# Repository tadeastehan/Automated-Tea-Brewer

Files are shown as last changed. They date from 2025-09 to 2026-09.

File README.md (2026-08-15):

<div align="center">

# Automated Tea Brewer

### Design and Implementation of a Fully Automated ESP32-Based Tea Brewer





`ESP32` · `Embedded Systems` · `C` · `FreeRTOS` · `LVGL` · `TMC2130` · `Stepper Motor` · `IoT`

[Repository](https://github.com/tadeastehan/Automated-Tea-Brewer) · [Documentation](#documentation) · [Getting Started](#project-structure)

</div>

---

<p align="center">
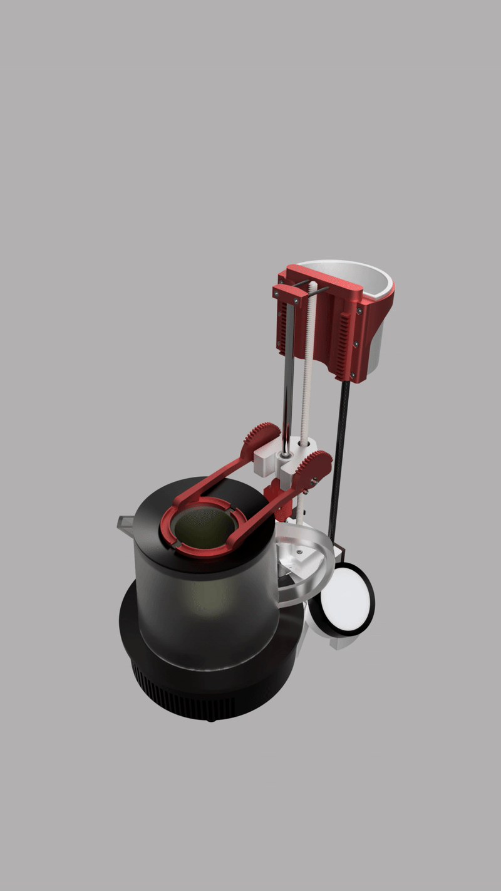
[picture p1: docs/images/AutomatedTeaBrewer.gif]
Automated Tea Brewer Animation
  
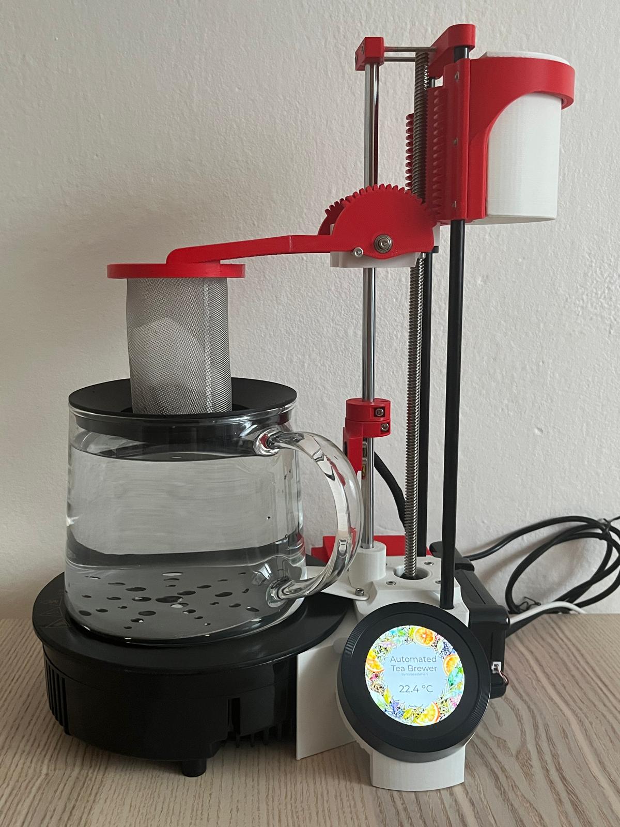
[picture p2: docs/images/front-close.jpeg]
Automated Tea Brewer Front View
  
</p>

## Project Annotation

This project presents the design and implementation of a **fully automated tea brewing system** based on ESP32 microcontrollers. The system consists of two ESP32 modules working in tandem:

| Module | Microcontroller | Function |
| --- | --- | --- |
| **Display Controller** | ESP32-S3 | Touchscreen UI using LVGL graphics library |
| **Motor Controller** | ESP32-C6 | Stepper motor control via TMC2130 driver |

### Key Features

- **IR Thermometer** - Precise water temperature monitoring
- **Laser Distance Sensor** - Teapot presence detection (VL53L0X)
- **Induction Cooker Interface** - Automated heating control via optocoupler
- **Stepper Motor Control** - Precise tea bag immersion with TMC2130
- **Touchscreen Interface** - Intuitive LVGL-based user interface
- **Web Dashboard** - Remote control via WiFi with mDNS support (teabrewer.local)
- **Programmable Brewing** - Configurable temperature, steeping time, and movement

> The goal was to create a fully autonomous tea brewing appliance that can prepare tea with consistent quality by precisely controlling brewing temperature, steeping time, and tea bag movement.

---

## Documents

| Document | Path |
| --- | --- |
| Paper | [View Paper](docs/paper/Design_and_Implementation_of_a_Fully_Automated_ESP32_Based_Tea_Brewer___Tadeáš_Těhan%20(3).pdf) |
| Images & Screenshots | [View Images](docs/images/) |

---

## Project Structure

```
Automated-Tea-Brewer/
├── src/                          # Source code
│   ├── tea-brewer/               # ESP32-S3 Display Controller
│   │   ├── main/
│   │   │   ├── app_main.c           # Application entry point
│   │   │   ├── uart_comm.c/h        # UART communication
│   │   │   ├── settings.c/h         # User settings management
│   │   │   ├── webserver.c/h        # Web dashboard server
│   │   │   └── ui/                  # LVGL user interface
│   │   ├── components/
│   │   │   ├── bsp/                 # Board Support Package
│   │   │   └── esp_lcd_touch_cst816s/
│   │   └── managed_components/      # ESP-IDF dependencies
│   │
│   └── tea-brewer-controller/    # ESP32-C6 Motor Controller
│       ├── main/
│       │   ├── main.c               # Application entry point
│       │   ├── motor/               # TMC2130 stepper control
│       │   ├── temperature_sensor/  # IR thermometer interface
│       │   ├── distance_sensor/     # VL53L0X laser sensor
│       │   ├── pot_sensor/          # Teapot detection
│       │   ├── protocol/            # ESP-to-ESP communication
│       │   ├── console/             # USB Serial debug interface
│       │   ├── scheduler.c/h        # Task scheduling
│       │   └── rtc/                 # Real-time clock
│       └── components/
│           └── vl53l0x/             # Distance sensor driver
│
├── docs/                         # Documentation
│   ├── electronics/                 # Electronics documentation
│   ├── images/                      # Project images & photos
│   ├── induction-cooker/            # Induction cooker mod guide
│   ├── stepper-motor-driver/        # TMC2130 wiring diagrams
│   └── web-dashboard/               # Web dashboard documentation
│
├── models/                       # 3D Models
│
└── reports/                      # Data & Analysis
    ├── brew-time/                   # Brew time analysis
    │   ├── graph_maker.py
    │   ├── data/
    │   └── graphs/
    ├── heat-dissipation/            # Heat dissipation analysis
    │   ├── graph_maker.py
    │   ├── data/
    │   └── graphs/
    └── ir-thermometer/              # IR thermometer calibration
        ├── graph_maker.py
        ├── data/
        └── graphs/
```

---

## Documentation

Hardware setup guides are available in the `docs/` folder:

- **[Induction Cooker Modification](docs/induction-cooker/induction_cooker.md)** - Optocoupler wiring and connector setup
- **[TMC2130 Stepper Driver](docs/stepper-motor-driver/TMC2130.md)** - SPI configuration and wiring diagrams
- **[Web Dashboard](docs/web-dashboard/web_dashboard.md)** - Remote control interface and API reference
- **[UI Documentation](src/ui/UI.md)** - LVGL UI structure and customization

---

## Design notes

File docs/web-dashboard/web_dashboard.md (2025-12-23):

# Tea Brewer Web Dashboard

The Tea Brewer includes a web-based dashboard that provides remote control and monitoring capabilities over WiFi. The dashboard mirrors the functionality of the physical LVGL display, allowing you to brew tea from any device on your network.

## Accessing the Dashboard

### Initial Setup (Captive Portal)

On first boot or after a WiFi reset, the Tea Brewer creates an Access Point (AP) for configuration:

1. **Connect to the AP** - Look for a WiFi network named `TeaBrewer` (or similar)
2. **Captive Portal** - A configuration page will automatically open
3. **Enter WiFi Credentials** - Provide your home WiFi network name and password
4. **Save & Connect** - The device will restart and connect to your network

### Accessing the Dashboard

Once connected to your WiFi network, access the dashboard via:

- **mDNS**: `http://teabrewer.local` (recommended)
- **IP Address**: Check your router or serial monitor for the assigned IP

## Dashboard Screenshot

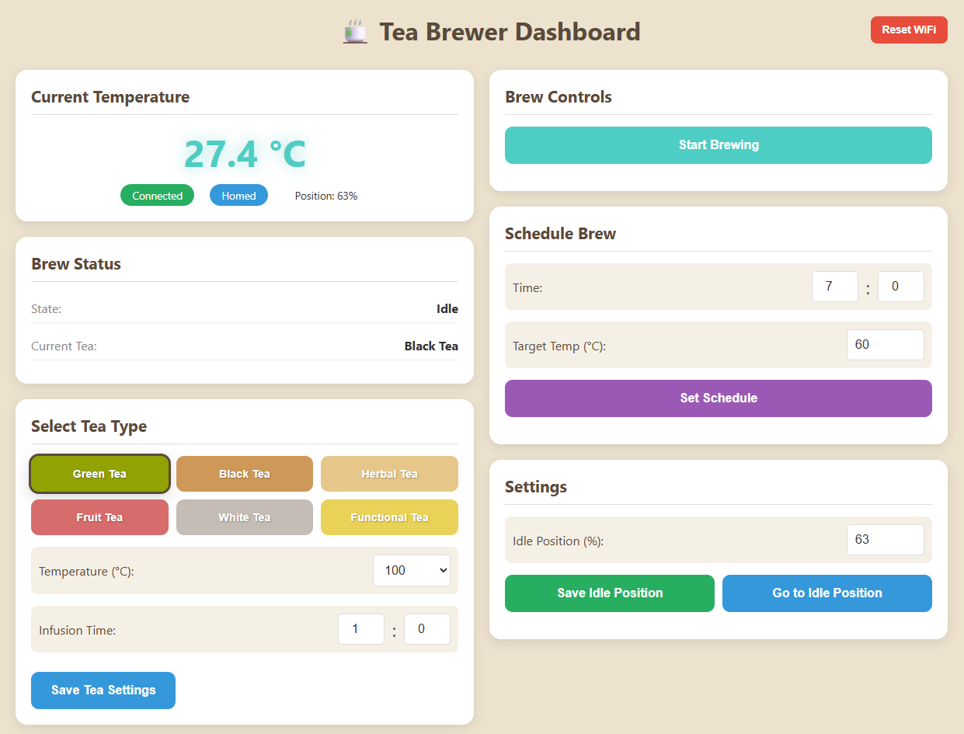
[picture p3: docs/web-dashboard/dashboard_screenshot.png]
Tea Brewer Dashboard


## Features

### Current Temperature
- **Real-time temperature display** with glowing effect
- **Motor status indicators**:
  - Connection status (Connected/Disconnected)
  - Homing status (Homed/Not Homed)
  - Current position percentage

### Brew Status
- **Current state**: Idle, Brewing, Infusing, Teabag Dropoff, or Scheduled
- **Current tea type** being brewed
- **Progress bar** during active brewing (shows percentage complete)

### Select Tea Type
- **6 tea types** with color-coded buttons:
  - Green Tea
  - Black Tea
  - Herbal Tea
  - Fruit Tea
  - White Tea
  - Functional Tea
- **Temperature setting** (75°C - 100°C in 5° increments)
- **Infusion time** configuration (minutes and seconds)
- **Save Tea Settings** button to persist changes

### Brew Controls
- **Start Brewing** - Begin brewing with the selected tea type
- **Stop** - Emergency stop during brewing

### Schedule Brew
- **Set time** (hour and minute) for scheduled brewing
- **Target temperature** for pre-heating
- **Set Schedule** / **Cancel Schedule** buttons
- Visual indicator showing scheduled time

### Settings
- **Idle Position** - Set and save the motor's idle/rest position
- **Go to Idle Position** - Move motor to the saved idle position

### Reset WiFi
- **Reset WiFi button** (top-right corner)
- Clears saved WiFi credentials
- Restarts device in AP mode for reconfiguration
- Confirmation dialog to prevent accidental resets

## Technical Details

### API Endpoints

| Endpoint | Method | Description |
|---|---|---|
| `/` | GET | Dashboard HTML page |
| `/api/status` | GET | Current system status (JSON) |
| `/api/tea/:index` | GET | Get tea settings for index 0-5 |
| `/api/tea/:index` | POST | Save tea settings |
| `/api/brew` | POST | Start brewing |
| `/api/brew/stop` | POST | Stop brewing |
| `/api/schedule` | POST | Set scheduled brew |
| `/api/schedule/cancel` | POST | Cancel scheduled brew |
| `/api/settings/idle_position` | POST | Save idle position |
| `/api/motor/go_idle` | POST | Move to idle position |
| `/api/wifi/reset` | POST | Reset WiFi and restart |

### Network Features

- **mDNS (Bonjour)** - Access via `teabrewer.local`
- **HTTP Server** - Port 80
- **Auto-refresh** - Status updates every 1 second
- **Toast Notifications** - Visual feedback for all actions

### Browser Compatibility

The dashboard works on all modern browsers:
- Chrome / Edge
- Firefox
- Safari (macOS / iOS)
- Android browsers

## Toast Notifications

The dashboard provides visual feedback through toast notifications:

| Action | Message | Type |
|---|---|---|
| Save tea settings | "Tea settings saved!" | Success |
| Start brew | "Brewing started!" | Success |
| Stop brew | "Brewing stopped" | Warning |
| Set schedule | "Schedule set for HH:MM" | Success |
| Cancel schedule | "Schedule cancelled" | Warning |
| Save idle position | "Idle position saved!" | Success |
| Go to idle | "Moving to idle position..." | Info |
| Reset WiFi | "Resetting WiFi..." | Warning |
| Any failure | "Failed to..." | Error |

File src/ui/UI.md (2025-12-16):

# Tea Brewer UI Documentation

## Overview

The Automated Tea Brewer uses **LVGL (Light and Versatile Graphics Library) v9.2.2** for its graphical user interface, designed using **SquareLine Studio 1.5.4**. The UI runs on an ESP32-S3 microcontroller with a round 480x480 display, providing an intuitive touch-based experience for brewing tea.

## Design Features

### Theme System

- **Dynamic Tea Colors**: The UI theme adapts based on the selected tea type, with each tea having its unique color scheme
- **Consistent Styling**: All screens share a common background and typography style using the Montserrat font family
- **Touch Optimized**: Large buttons (100x100 px) ensure easy interaction on the touchscreen

### Tea Types and Colors

The system supports 6 tea types, each with a distinct color:

| Tea Type | Color Code | Description |
| --- | --- | --- |
| Green Tea | `#92A202`  | <code style="color: #92A202">Vibrant green</code> |
| Black Tea | `#CE9958`  | <code style="color: #CE9958">Warm brown</code> |
| Herbal Tea | `#E7C789`  | <code style="color: #E7C789">Soft golden</code> |
| Fruit Tea | `#D76C6C`  | <code style="color: #D76C6C">Coral red</code> |
| White Tea | `#C4BCB5`  | <code style="color: #C4BCB5">Subtle gray</code> |
| Functional Tea | `#E9D257`  | <code style="color: #E9D257">Bright yellow</code> |

## Screen Descriptions

### 1. Main Screen

The welcome screen displaying the "Automated Tea Brewer" title with the current temperature.

- **Tap Left Side**: Navigate to Settings Screen
- **Tap Right Side**: Navigate to Tea Screen (starts with Green Tea)

### 2. Tea Screen

Displays the currently selected tea type with a themed background image.

- **Begin Button** (Play icon): Navigate to Brew Now or Scheduler Screen
- **Edit Button** (Cookie icon): Navigate to Tea Properties Screen
- **Tap Right Side**: Navigate to next tea (on last tea → Settings Screen)
- **Tap Left Side**: Navigate to previous tea (on first tea → Main Screen)

> **Navigation Loop**: Main Screen → Green Tea → Black Tea → Herbal Tea → Fruit Tea → White Tea → Functional Tea → Settings Screen → Main Screen (circular)

### 3. Tea Properties Screen

Configure brewing parameters for the selected tea:

- **Temperature Roller**: Set brewing temperature (75°C - 100°C in 5°C increments)
- **Infusion Time Rollers**: Set minutes (0-14) and seconds (0-59)
- **Return Button** (Check icon): Save and return to Tea Screen

### 4. Brew Now or Scheduler Screen

Choose between immediate brewing or scheduled brewing:

- **Brew Now Button** (Coffee cup icon): Start brewing immediately
- **Schedule Button** (Clock icon): Navigate to Scheduler Screen
- **Cancel Button** (X icon): Return to Tea Screen

### 5. Teapot Screen

Instructions to place the teapot with water on the designated area.

- Displays a teapot image with placement instructions
- Automatically proceeds when pot is detected

### 6. Brew/Infuse Screen

Active brewing progress display:

- **Progress Arc**: Visual indicator of brewing progress
- **Temperature Display**: Current and target temperature
- **Stop Button** (Stop icon): Cancel brewing and return to Tea Screen

### 7. Scheduler Screen

Configure scheduled brewing:

- **Temperature Roller**: Set target temperature (75°C - 100°C)
- **Time Rollers**: Set hour (0-23) and minute (0-59) for scheduled start
- **Confirm Button** (Check icon): Start scheduled brewing → Navigate to Scheduled Screen
- **Cancel Button** (X icon): Return to Tea Screen

### 8. Scheduled Screen

Displays scheduled brewing information:

- Shows target temperature and scheduled time
- **Cancel Button** (Stop icon): Cancel scheduled brewing and return to Tea Screen

### 9. Settings Screen

Configure system settings:

- **Idle Position Controls**: Adjust the teabag holder idle position (+/- buttons)
- **Tap Left Side**: Navigate to last tea (Functional Tea)
- **Tap Right Side**: Navigate to Main Screen

### 10. Error Screen

Displays error information when issues occur:

- **Error Text Area**: Shows detailed error message
- **Acknowledge Button** (Check icon): Return to Tea Screen

---

## Tea Brewer UI Navigation Map

```mermaid
flowchart TD
    subgraph Main["Main Screen"]
        MS[Automated Tea Brewer<br/>Shows current temperature]
    end

    subgraph TeaSelection["Tea Selection"]
        TS[Tea Screen<br/>Shows tea type & background]
    end

    subgraph TeaConfig["Tea Configuration"]
        TPS[Tea Properties Screen<br/>Temperature & Infusion Time]
    end

    subgraph BrewChoice["Brew Options"]
        BNOS[Brew Now or Scheduler Screen<br/>Choose brew timing]
    end

    subgraph Brewing["Active Brewing"]
        POT[Teapot Screen<br/>Place teapot instruction]
        BIS[Brew/Infuse Screen<br/>Progress & Controls]
    end

    subgraph Scheduling["Scheduling"]
        SCH[Scheduler Screen<br/>Set time & temperature]
        SCHD[Scheduled Screen<br/>Shows scheduled info]
    end

    subgraph Settings["Settings"]
        SET[Settings Screen<br/>Idle position controls]
    end

    subgraph Errors["Error Handling"]
        ERR[Error Screen<br/>Error details]
    end

    %% Main Navigation
    MS -->|"Tap Right Side"| TS
    MS -->|"Tap Left Side"| SET

    %% Tea Screen Navigation
    TS -->|"Tap Right Side<br/>(next tea)"| TS
    TS -->|"Tap Left Side<br/>(previous tea)"| TS
    TS -->|"First tea<br/>Tap Left Side"| MS
    TS -->|"Last tea<br/>Tap Right Side"| SET
    TS -->|"Begin Button<br/>(Play icon)"| BNOS
    TS -->|"Edit Button<br/>(Cookie icon)"| TPS

    %% Tea Properties Navigation
    TPS -->|"Return Button<br/>(Check icon)"| TS

    %% Brew Now or Scheduler Navigation
    BNOS -->|"Cancel Button<br/>(X icon)"| TS
    BNOS -->|"Brew Now Button<br/>(Coffee cup)"| POT
    BNOS -->|"Schedule Button<br/>(Clock icon)"| SCH

    %% Teapot Screen Navigation
    POT -->|"Pot detected<br/>(automatic)"| BIS

    %% Brew/Infuse Screen Navigation
    BIS -->|"Stop Button<br/>(Stop icon)"| TS
    BIS -->|"Brewing Complete<br/>(automatic)"| TS

    %% Scheduler Screen Navigation
    SCH -->|"Cancel Button<br/>(X icon)"| TS
    SCH -->|"Confirm Button<br/>(Check icon)"| SCHD

    %% Scheduled Screen Navigation
    SCHD -->|"Cancel Button<br/>(Stop icon)"| TS
    SCHD -->|"Scheduled time reached"| POT

    %% Settings Navigation
    SET -->|"Tap Right Side"| MS
    SET -->|"Tap Left Side"| TS

    %% Error Screen Navigation
    ERR -->|"Acknowledge Button<br/>(Check icon)"| TS

    %% Error can occur from multiple screens
    BIS -.->|"Error occurs"| ERR
    POT -.->|"Error occurs"| ERR

    %% Styling
    style MS fill:#1a1a2e,stroke:#92A202,color:#fff
    style TS fill:#1a1a2e,stroke:#92A202,color:#fff
    style TPS fill:#1a1a2e,stroke:#CE9958,color:#fff
    style BNOS fill:#1a1a2e,stroke:#E7C789,color:#fff
    style POT fill:#1a1a2e,stroke:#D76C6C,color:#fff
    style BIS fill:#1a1a2e,stroke:#FF5B2B,color:#fff
    style SCH fill:#1a1a2e,stroke:#E9D257,color:#fff
    style SCHD fill:#1a1a2e,stroke:#E9D257,color:#fff
    style SET fill:#1a1a2e,stroke:#C4BCB5,color:#fff
    style ERR fill:#1a1a2e,stroke:#FF0000,color:#fff
```

---

## Screen Gallery

| Screen Name | Screenshot |
| --- | --- |
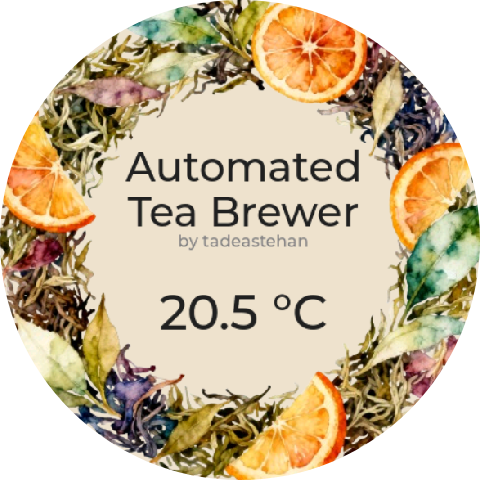
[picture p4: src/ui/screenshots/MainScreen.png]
Main Screen
| Main Screen |  |
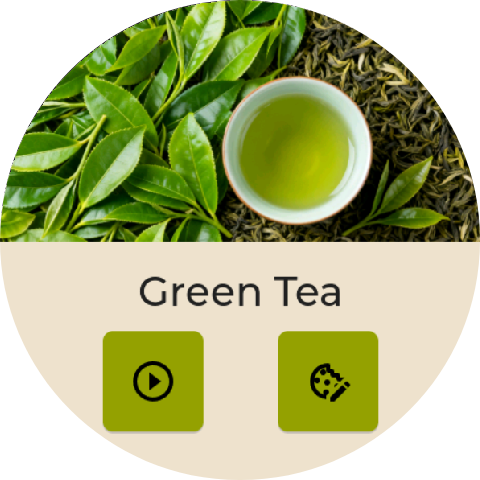
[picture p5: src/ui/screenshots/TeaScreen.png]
Tea Screen
| Tea Screen |  |
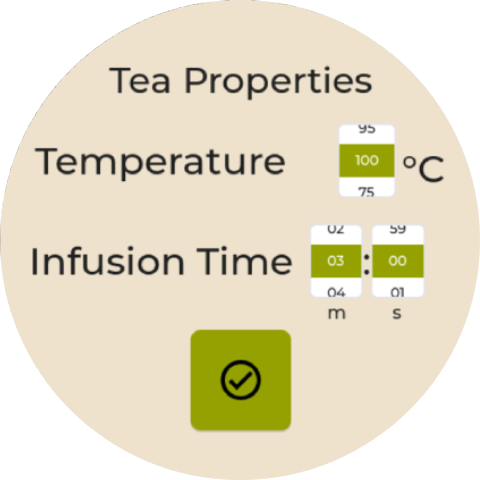
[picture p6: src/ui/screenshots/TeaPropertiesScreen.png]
Tea Properties Screen
| Tea Properties Screen |  |
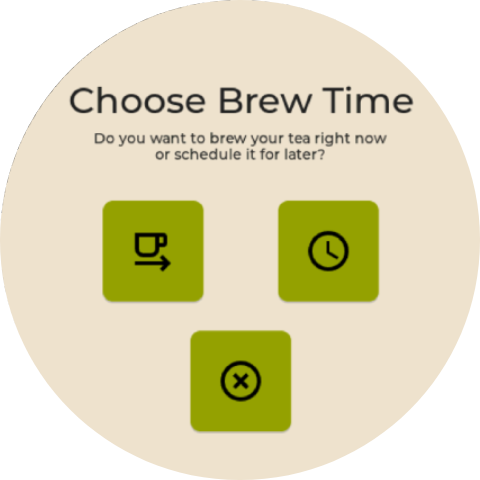
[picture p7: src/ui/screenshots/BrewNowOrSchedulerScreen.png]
Brew Now or Scheduler Screen
| Brew Now or Scheduler Screen |  |
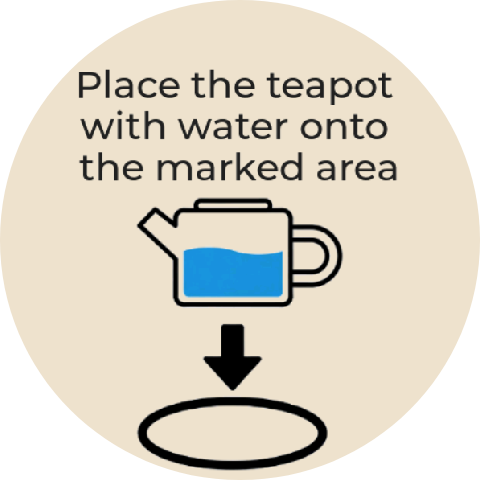
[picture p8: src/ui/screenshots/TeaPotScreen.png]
Teapot Screen
| Teapot Screen |  |
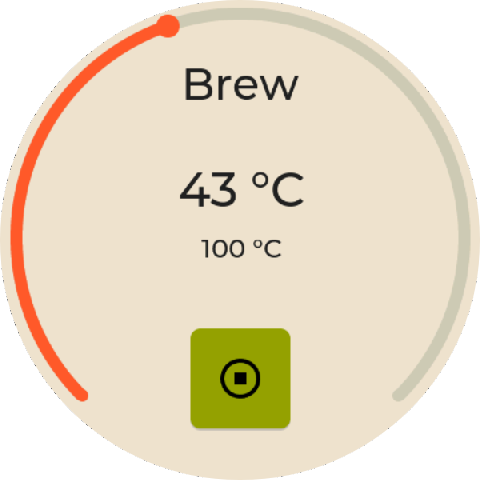
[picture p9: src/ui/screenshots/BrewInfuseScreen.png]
Brew/Infuse Screen
| Brew/Infuse Screen |  |
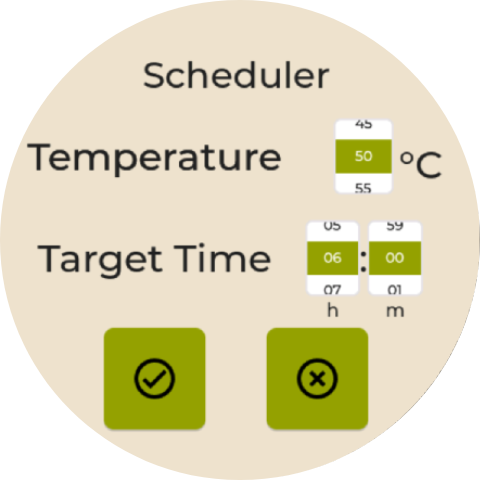
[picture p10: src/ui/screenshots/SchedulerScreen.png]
Scheduler Screen
| Scheduler Screen |  |
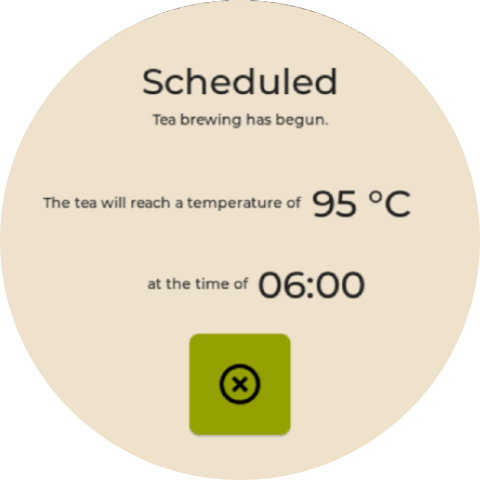
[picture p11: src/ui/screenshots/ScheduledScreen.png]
Scheduled Screen
| Scheduled Screen |  |
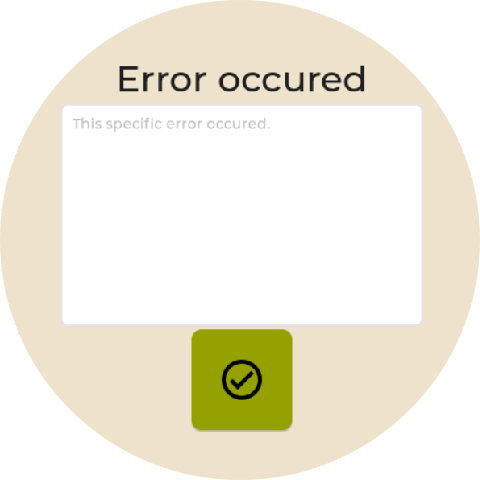
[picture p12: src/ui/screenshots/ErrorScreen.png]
Error Screen
| Error Screen |  |
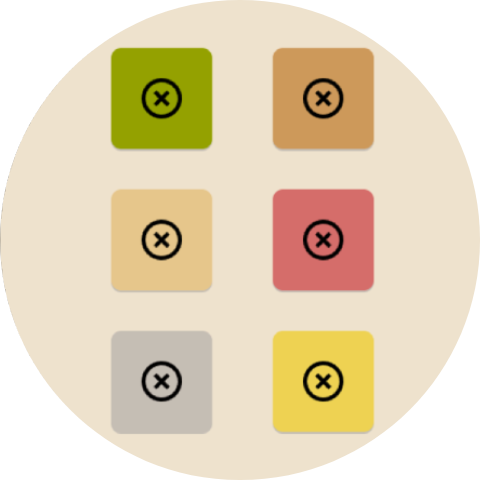
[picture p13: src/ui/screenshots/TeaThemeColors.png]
Tea Theme Colors
| Tea Theme Colors |  |

---

## Technical Details

### Screen IDs

```c
#define UI_SCREEN_MAIN              0
#define UI_SCREEN_TEA               1
#define UI_SCREEN_TEAPOT            2
#define UI_SCREEN_BREW_INFUSE       3
#define UI_SCREEN_ERROR             4
#define UI_SCREEN_TEA_PROPERTIES    5
#define UI_SCREEN_BREW_NOW_OR_SCHEDULER 6
#define UI_SCREEN_SETTINGS          7
#define UI_SCREEN_SCHEDULER         8
#define UI_SCREEN_SCHEDULED         9
```

### File Structure

```
src/tea-brewer/main/ui/
├── ui.c / ui.h              # Main UI initialization
├── ui_events.c / ui_events.h # Event handlers
├── ui_helpers.c / ui_helpers.h # Helper functions
├── ui_themes.c / ui_themes.h # Theme definitions
├── screens/                  # Individual screen files
│   ├── ui_MainScreen.c/h
│   ├── ui_TeaScreen.c/h
│   ├── ui_TeaPropertiesScreen.c/h
│   ├── ui_BrewNowOrSchedulerScreen.c/h
│   ├── ui_TeapotScreen.c/h
│   ├── ui_BrewInfuseScreen.c/h
│   ├── ui_SchedulerScreen.c/h
│   ├── ui_ScheduledScreen.c/h
│   ├── ui_SettingsScreen.c/h
│   └── ui_ErrorScreen.c/h
├── fonts/                    # Font assets
└── images/                   # Image assets
```

### SquareLine Studio Project

The UI design source files are located in:

```
src/ui/SquareLine-Project/
├── Automated-Tea-Brewer.spj  # Main project file
├── Automated-Tea-Brewer.sll  # Layout file
├── Themes.slt                # Theme definitions
└── assets/                   # Design assets
```

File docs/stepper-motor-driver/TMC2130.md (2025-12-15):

# TMC2130

The TMC2130 is a popular stepper motor driver known for its quiet operation and advanced features. It is widely used in 3D printers, CNC machines, and other applications requiring precise motor control.

## SPI Interface

> [!IMPORTANT]
> Important for proper operation: The TMC2130 V1.1 must be configured to operate in SPI mode. By default, it may be set to a different mode, so the following modifications are necessary.

The TMC2130 communicates via the SPI (Serial Peripheral Interface) protocol. This allows for high-speed data transfer and the ability to configure various parameters of the driver.
To switch the TMC2130 V1.1 into SPI mode:

- unsolder the `R5` resistor on the driver board (red rectangle in the image).
- solder `CFG4` to `GND` (purple rectangle in the image).
- solder `CFG5` to `VIO` (pink rectangle in the image).
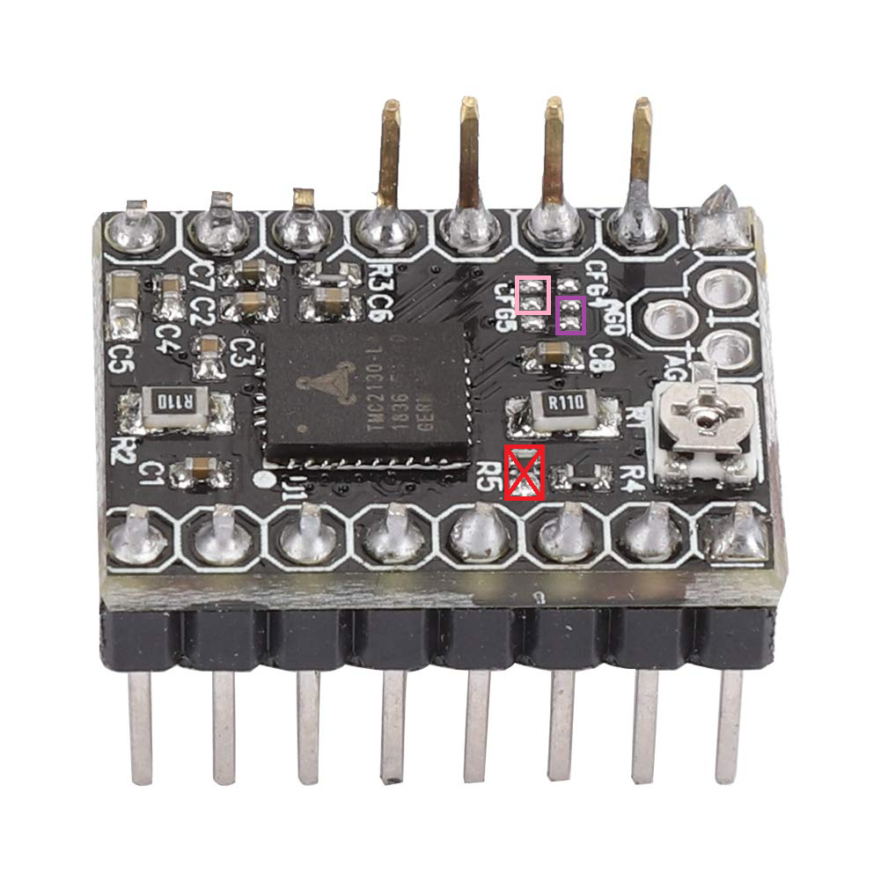
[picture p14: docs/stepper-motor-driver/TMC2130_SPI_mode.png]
TMC2130 SPI Mode
  

## Wiring
When using the TMC2130 in SPI mode, the following connections are typically made:
- **GND**: Connect to ground.
- **VIO**: Connect to 3.3V or 5V logic level (depending on your microcontroller).
- **M1A, M1B, M2A, M2B**: Connect to the stepper motor coils.
- **VM**: Connect to the motor power supply (typically 12V or 24V).
- **EN**: Connect to a digital pin on the microcontroller to enable/disable the driver.
- **SDI**: Connect to the microcontroller's MOSI pin.
- **SCK**: Connect to the microcontroller's SCK pin.
- **CS**: Connect to a digital pin on the microcontroller to select the TMC2130.
- **SDO**: Connect to the microcontroller's MISO pin.
- **STEP**: Connect to a digital pin on the microcontroller to control stepping.
- **DIR**: Connect to a digital pin on the microcontroller to control direction.
See the wiring diagram[^1] below for reference:
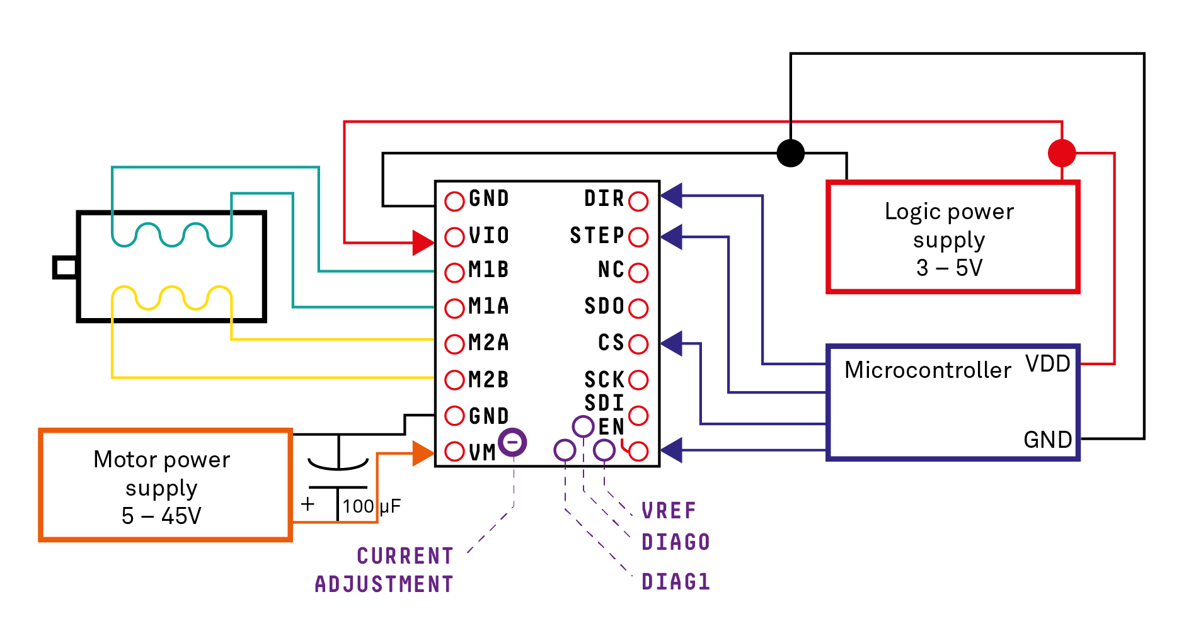
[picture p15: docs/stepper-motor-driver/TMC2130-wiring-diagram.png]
TMC2130 Wiring Diagram


[^1]: [TMC2130 Arduino Wiring](https://www.julian-h.de/sketch/tmc2130-arduino-wiring/)

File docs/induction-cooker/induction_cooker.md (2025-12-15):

# Induction Cooker

## Prerequisites

### Optocoupler

Optocoupler is required to isolate the high voltage part of the induction cooker from the low voltage ESP32 controller. We recommend using `PC817` optocoupler.
To use the induction cooker with ESP32 we need to modify the hardware slightly. So we open the induction cooker and controller board and connect `PC817` optocoupler pins `emitter` to the one leg of a button and `collector` to the other leg of the button. Then between the `anode` and connector pins of the optocoupler we connect a `150 Ω` resistor in series (I = 20mA at 3.3V).
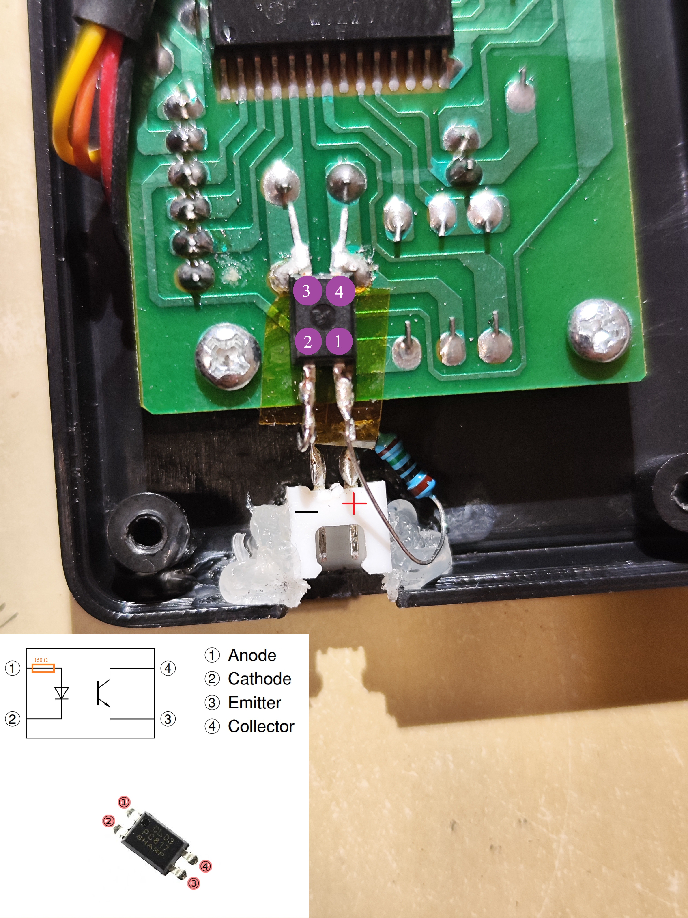
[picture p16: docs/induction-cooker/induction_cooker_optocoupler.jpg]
Induction Cooker Optocoupler Connection


### Connector

The best connector to use is JST XH 2.54mm 2-pin connector.
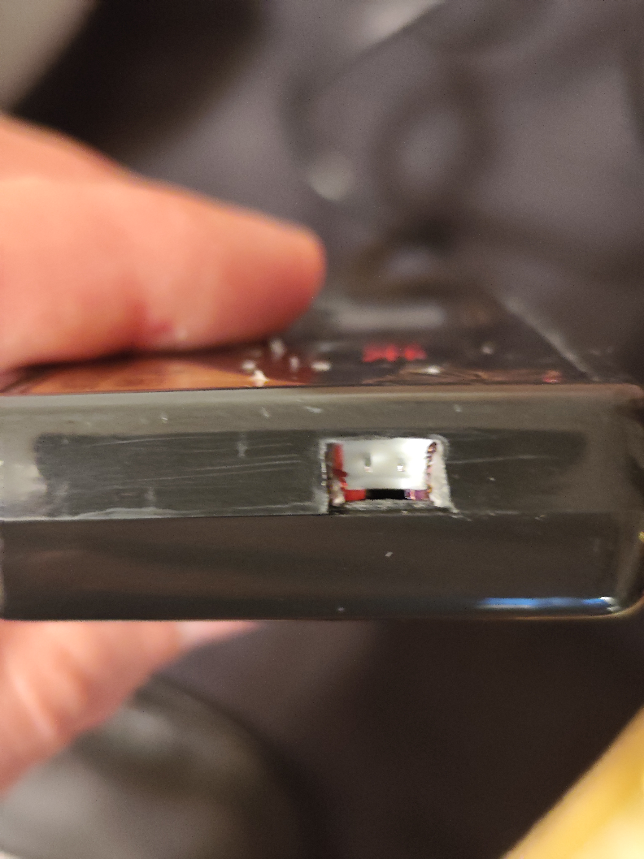
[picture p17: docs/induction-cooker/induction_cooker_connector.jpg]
Induction Cooker Connector


### Wiring
An IR thermometer with a laser distance sensor measures the temperature of the teapot's glass surface, while the laser distance sensor detects whether a teapot is present on the induction cooker. Both components are housed in the same 3D printed case. Since they share a single connector, you only need to connect the IR thermometer connector as shown in the wiring diagram below.

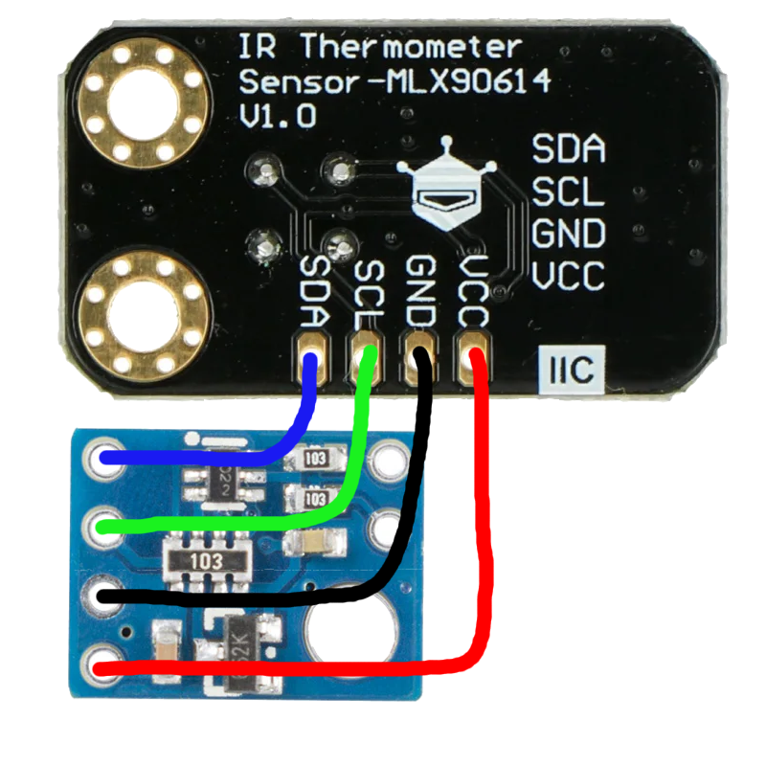
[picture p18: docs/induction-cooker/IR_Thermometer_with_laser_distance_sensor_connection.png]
IR Themometer connected with laser distance sensor


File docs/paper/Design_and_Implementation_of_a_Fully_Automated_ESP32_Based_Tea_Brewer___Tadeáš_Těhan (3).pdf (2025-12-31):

# Design and Implementation of a Fully Automated ESP32-Based Tea Brewer

Tade´aˇs Tˇehan

github.com/tadeastehan/Automated-Tea-Brewer

## Abstract

For students and busy users who need a large amount of tea ready for the whole day, existing tea makers either require constant manual attention or only prepare a single cup at a time. This paper presents the design and implementation of a fully automated tea brewing system capable of preparing 1.5 liters of tea with minimal user intervention. Unlike existing tea brewing solutions that focus on single-cup applications or require manual tea bag removal, this project addresses the practical need for large-volume, long-duration tea preparation. The system automatically heats water using induction cooking, submerges the mesh infuser with tea bag for optimal infusion, and automatically removes and disposes of the spent tea bag into a waste bin. An ESP32-based microcontroller system controls the entire process with a touchscreen interface and scheduling capabilities, allowing users to program tea preparation for specific times. The primary innovation lies in the compact mechanical design of the automated tea bag removal mechanism, utilizing a stepper motor with a threaded rod and dual-gear system. This solution overcomes critical engineering challenges including non-inductive glass compatibility, temperature measurement calibration, and mechanical precision in gear engagement. The completed prototype successfully demonstrates all core functionalities with reliable operation across multiple tea brewing cycles.

## Solution and Implementation

The automated tea brewer integrates mechanical, electrical, and software components to create a seamless user experience. The system architecture comprises several interconnected subsystems: (1) an induction heating module that heats water in a standard glass teapot, (2) an infuser positioning mechanism for submerging and infusing tea bags, (3) temperature monitoring via infrared sensors, and (4) an ESP32-based control system with touchscreen interface and Wi-Fi connectivity.

Water Heating via Induction

Heating water efficiently and safely presented the initial design challenge. While submersible heating coils and electric resistance elements were considered, they proved either operationally complex or difficult to control precisely due to slow thermal response times, which would result in excessively long brewing cycles. Induction cooking was selected for its rapid heating and instantaneous on-off control. However, standard glass teapots are nonconductive and incompatible with induction cooktops. The solution involved deploying a submersible stainless steel conversion adapter placed directly in the water. This approach maximizes heat transfer efficiency compared to contact-based adapters while requiring periodic cleaning. The induction cooktop is controlled via optoisolated phototransistor circuits that simulate user button presses, ensuring galvanic isolation between the high-voltage induction unit and the low-voltage control electronics.

The Automated Tea Bag Removal Mechanism: Core Innovation

The most significant technical achievement is the design of the automated tea bag removal and disposal system. Initial design iterations explored using a servo motor combined with a chain-drive mechanism to lift the mesh infuser, but this approach generated excessive mechanical stress on the chain and proved unreliable. A robotic arm configuration was subsequently evaluated but deemed excessively complex for the application. The final solution employs a stepper motor driving a threaded rod mechanism coupled with a dual-gear system to rotate the tea infuser linearly along the z-axis. This arrangement provides smooth, controlled vertical motion while minimizing mechanical complexity.

The gear design required meticulous engineering to achieve proper contact geometry and force distribution. Critical parameters included gear spacing calibration, threaded rod tightness adjustment, and bearing alignment. A linear bearing guides the z-axis carriage, ensuring smooth operation without binding or excessive play. Multiple iterations of 3D-printed prototypes were necessary to fine-tune the gear mesh tolerances and ensure reliable engagement between the circular gear and linear rack at the ejection position

The stepper motor provides precise positional control, enabling the infuser to descend fully into the hot water, remain submerged for the programmed infusion duration,

1

and rise completely to position the tea bag over a waste bin. In the upper position, the circular gear wheel on the infuser engages with a fixed linear gear rack, which rotates the infuser and releases the used tea bag into the collection container. This single-motor, dual-gear approach elegantly solves the automation challenge while maintaining mechanical simplicity and high reliability compared to more complex chain-driven systems.

Temperature Monitoring and Calibration

Accurate temperature measurement is essential for scheduling delayed brewing and ensuring optimal tea infusion temperatures. The system implements an infrared (IR) thermometer pointed at the glass teapot surface. However, IR measurements detect surface temperature rather than internal water temperature. To establish the relationship between glass surface temperature and actual water temperature, a polynomial fitting procedure was performed: water temperature was measured independently while simultaneously recording IR surface readings across the full heating and cooling curve. A seconddegree polynomial function was fitted to this data, enabling the firmware to calculate true water temperature from IR readings with an RMS error of 0.78°C. This calibration procedure accounts for the glass thermal properties and measurement angle effects.

Additionally, detailed heat dissipation measurements were conducted by recording temperature decrease over extended periods (10+ hours) to characterize how quickly water cools inside the teapot. These measurements are critical for the scheduler functionality: they enable the system to calculate precisely when to initiate heating so that the water reaches the target infusion temperature at the user’s desired completion time, accounting for natural cooling during the brewing process.

Control System and User Interface

The control system employs two coordinated ESP32 microcontrollers. The primary ESP32 manages the touchscreen display and user interface, while the secondary controller ESP32 handles the critical automation tasks: driving the stepper motor via a dedicated stepper motor driver, controlling the induction cooktop through optoisolated circuits, acquiring infrared temperature measurements, monitoring pot presence via laser distance sensor, and maintaining timing through an integrated real-time clock (RTC) module. This dual-microcontroller architecture was necessary because the touchscreen display alone consumes a significant number of GPIO pins, leaving insufficient pins on a single ESP32 for all system peripherals and control functions.

The firmware implements a state-machine architecture managing the complete tea preparation sequence: heating initialization, temperature monitoring, infuser descent, infusion timer, infuser ascent, and waste disposal. The user interface provides selection from six predefined tea profiles: green, black, herbal, fruit, functional, and white. Each profile includes customizable parameters for target infusion temperature and infusion duration. The scheduler feature enables users to set a desired completion time; the controller ESP32’s RTC automatically calculates the required heating start time based on measured heat dissipation rates and initiates the process accordingly. Safety watchdog logic prevents heating without a detected teapot, enforced via the laser distance sensor. Multiple fail-safe mechanisms disable heating: absence of pot detection, sensor fault conditions, and excessive brewing duration beyond a predefined timeout. This layered approach ensures safe operation under all failure scenarios.

## Conclusions and Future Work

This project successfully demonstrates that practical large-volume tea brewing automation is technically feasible and operationally superior to existing solutions. The completed system meets all primary objectives: reliable 1.5-liter brewing capacity, consistent quality across multiple brewing cycles, intuitive user control, and scheduled preparation capability. The most valuable contribution is the innovative tea bag removal mechanism, which provides a robust alternative to traditional chain-driven approaches and could serve as a reference design for other dispensing applications.

Significant challenges were encountered and resolved during implementation, including component sourcing delays (defective induction cooktop requiring replacement), thermal calibration complexity, and mechanical precision requirements for gear engagement. The choice of ASA material for 3D-printed components proved appropriate given thermal exposure and UV resistance requirements.

The primary incompleteness is the absence of a rotary carousel storage system for multiple tea bag varieties. Initial design iterations proved complex, and time constraints necessitated manual loading of individual tea bags into the infuser. This functionality remains clearly defined for future enhancement and represents the natural next step in the system’s evolution.

Despite these limitations, the prototype delivers a genuinely unique solution addressing a practical gap in the market. The system proves that full automation at the 1.5-liter scale is achievable, differentiating it from all identified prior projects. The elegant mechanical design, robust embedded systems implementation, and user-centric interface collectively demonstrate successful engineering across multiple domains.

2

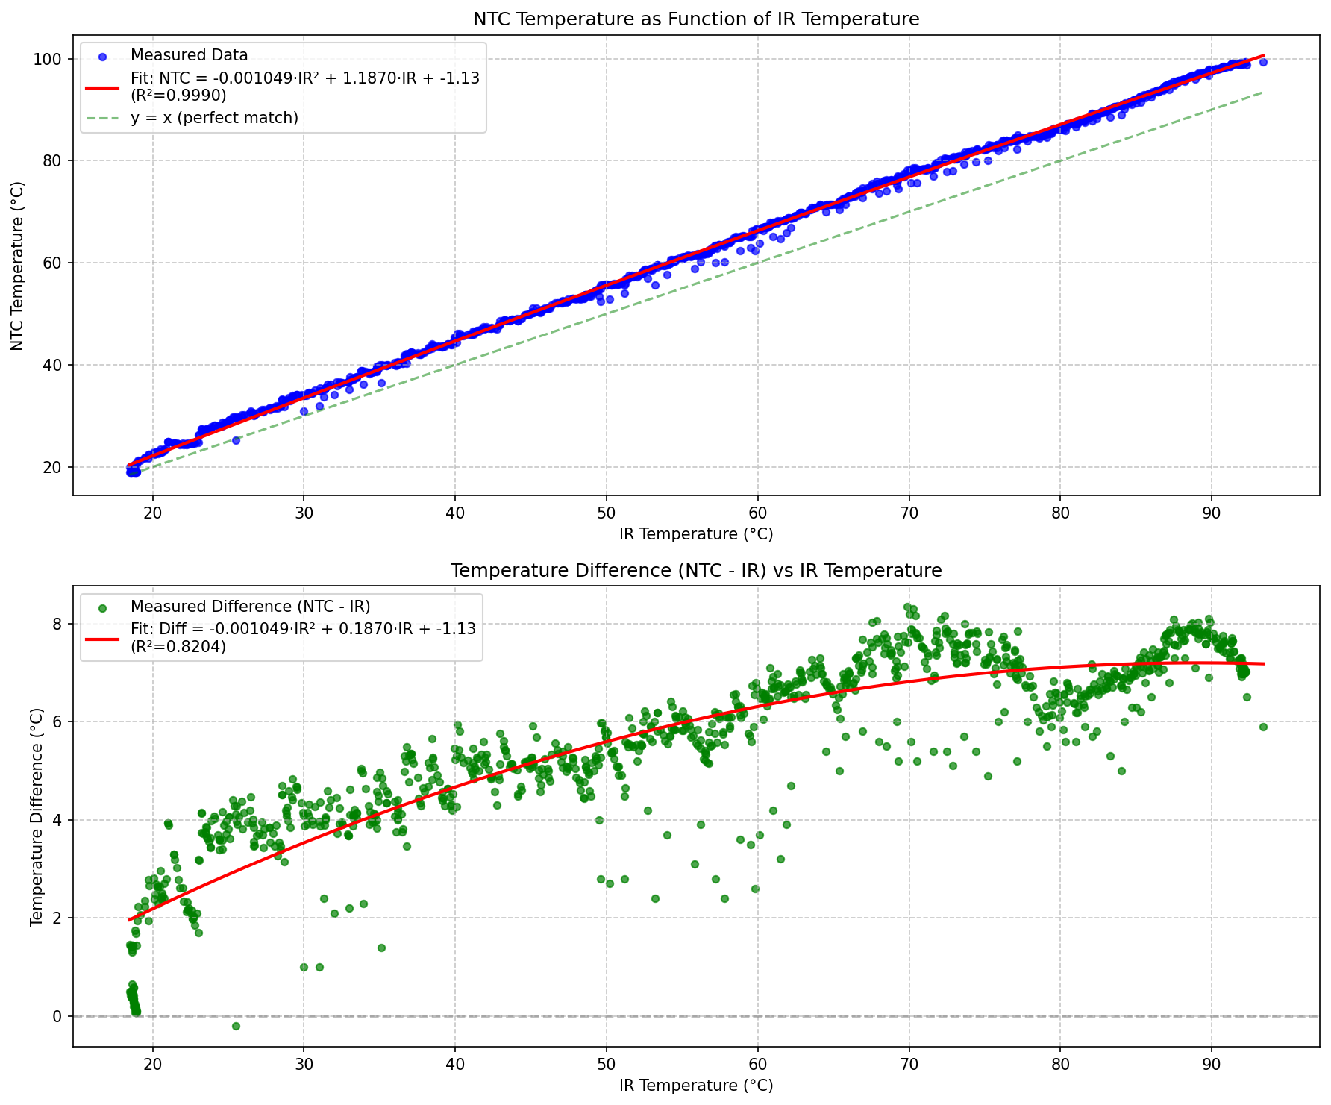
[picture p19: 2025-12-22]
reports/ir-thermometer/graphs/temperature_comparison.png

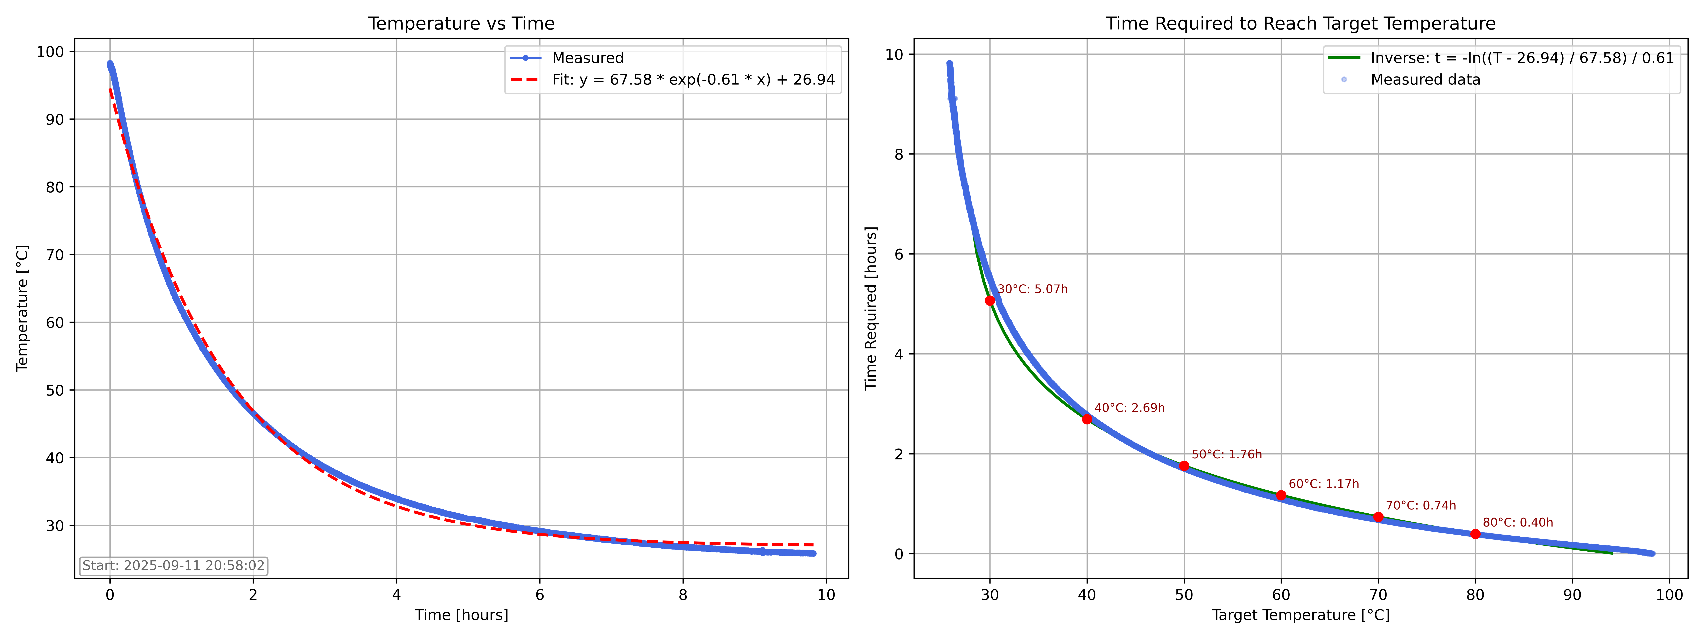
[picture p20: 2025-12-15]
reports/heat-dissipation/graphs/heat_dissipation_plot.png

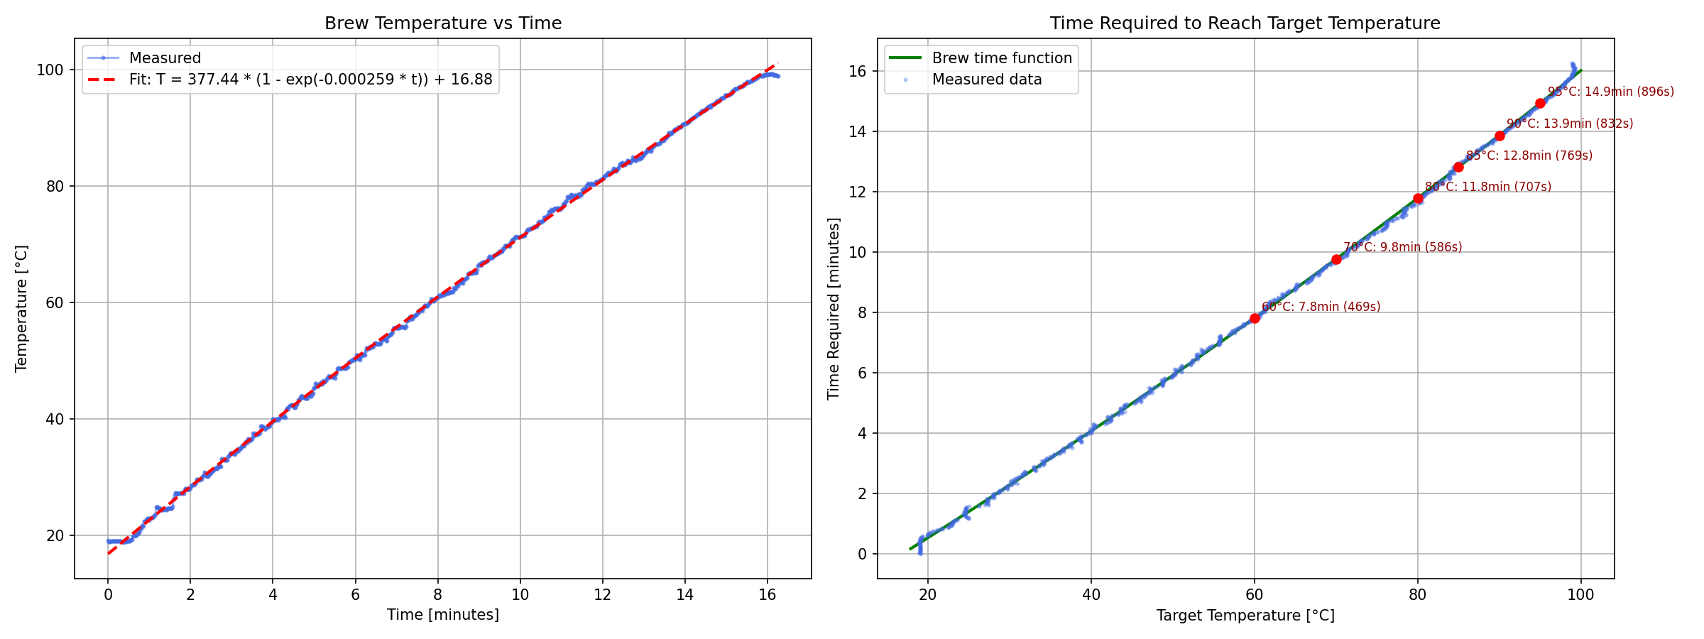
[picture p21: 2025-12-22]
reports/brew-time/graphs/brew_time_plot.png

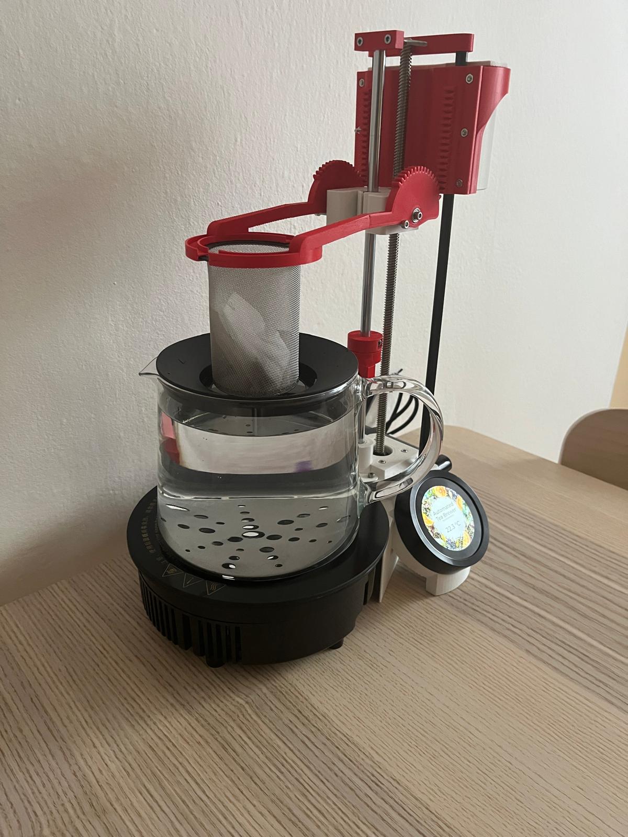
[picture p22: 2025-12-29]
docs/images/front-left.jpeg

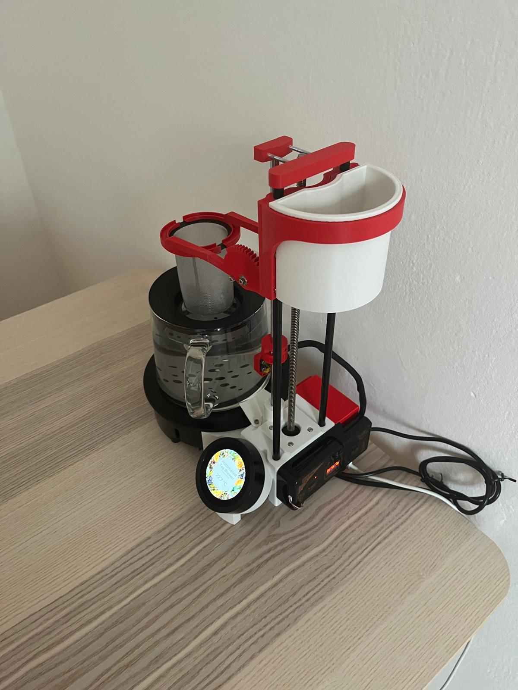
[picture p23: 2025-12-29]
docs/images/front-right-top.jpeg

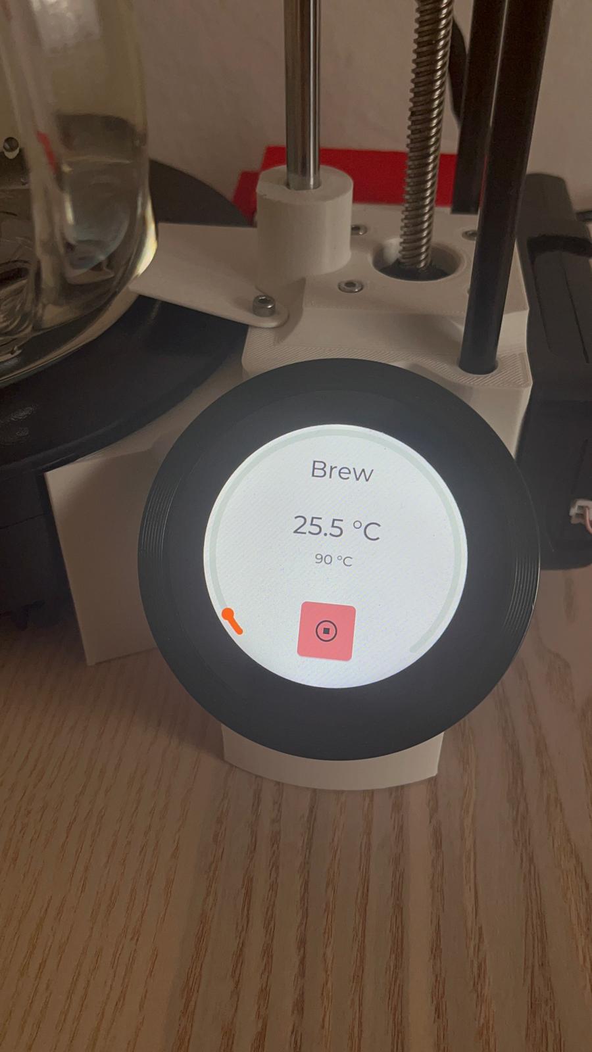
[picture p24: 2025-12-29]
docs/images/display-close-brew.jpeg

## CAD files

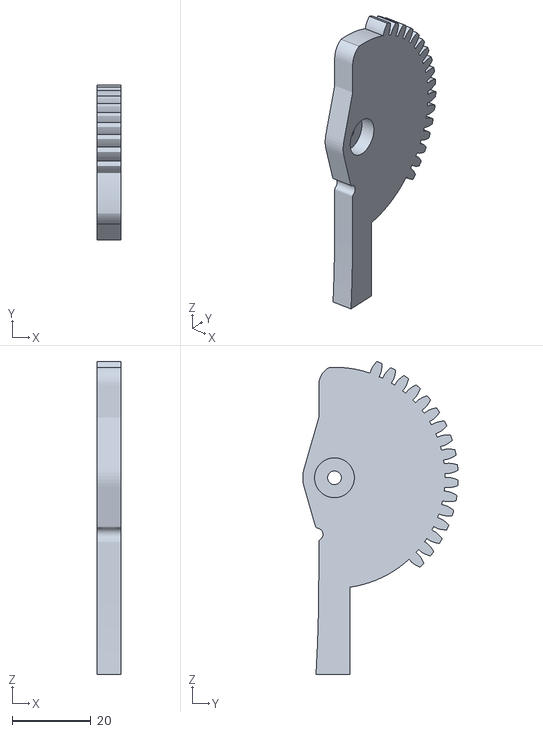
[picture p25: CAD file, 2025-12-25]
models/Right Arm Gear.stl
6.00 x 39.6 x 79.7

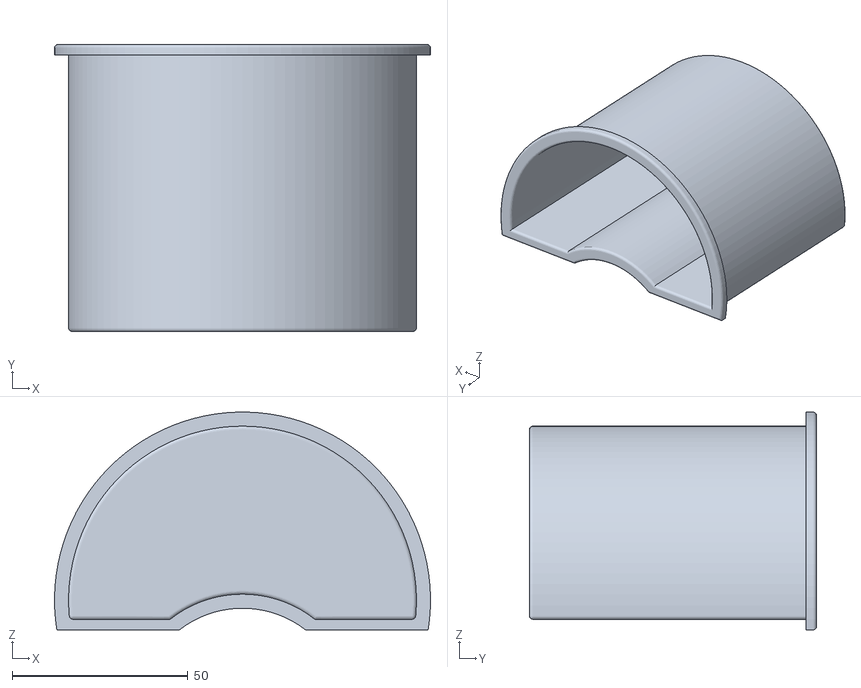
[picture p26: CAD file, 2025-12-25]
models/End Brake Basket.stl
106.8 x 81.6 x 61.9

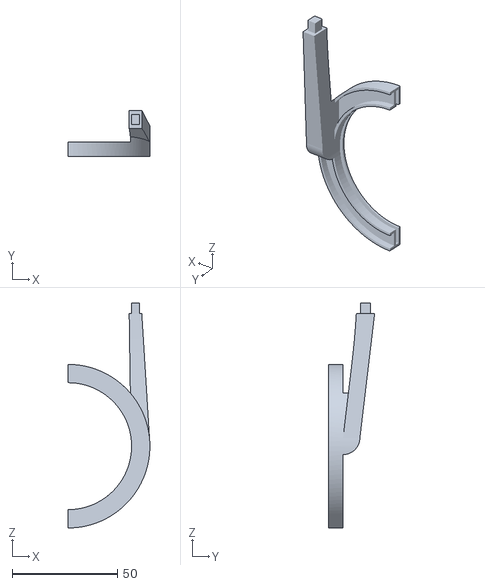
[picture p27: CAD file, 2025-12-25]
models/Right Arm Hand.stl
38.8 x 22.0 x 106.8

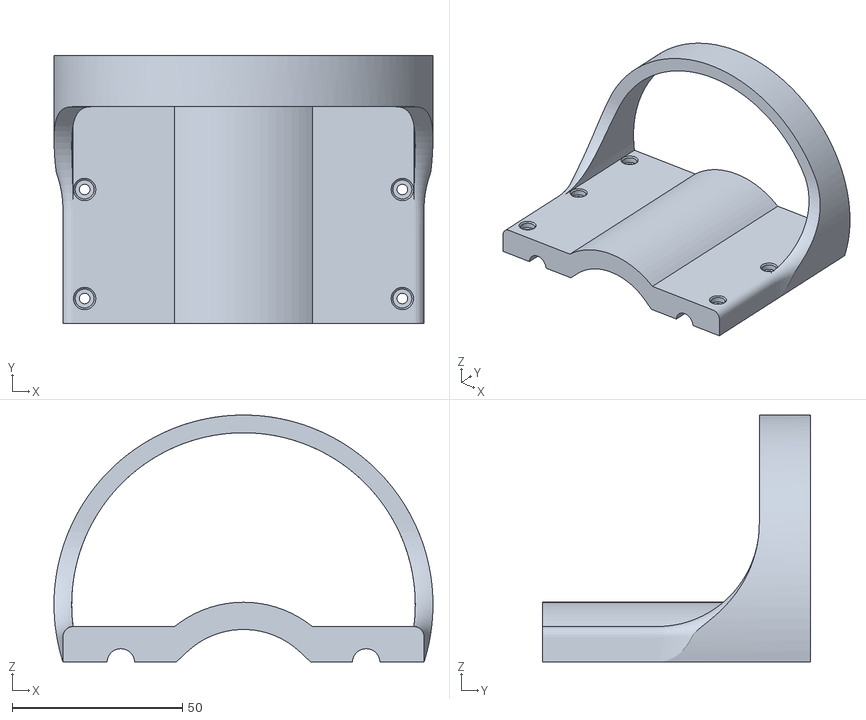
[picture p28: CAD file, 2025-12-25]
models/End Brake Part 2.stl
111.2 x 78.6 x 72.5

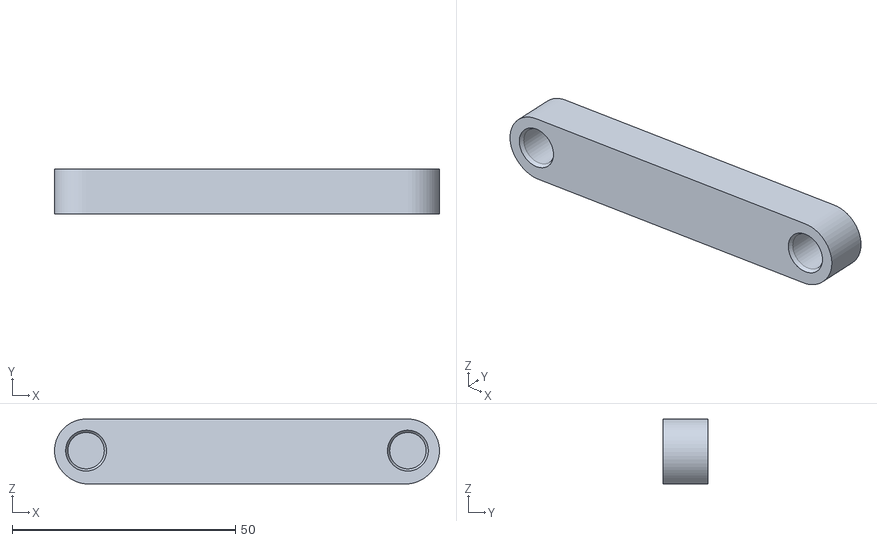
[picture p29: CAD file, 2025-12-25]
models/Tightener A.stl
86.1 x 10.0 x 14.5

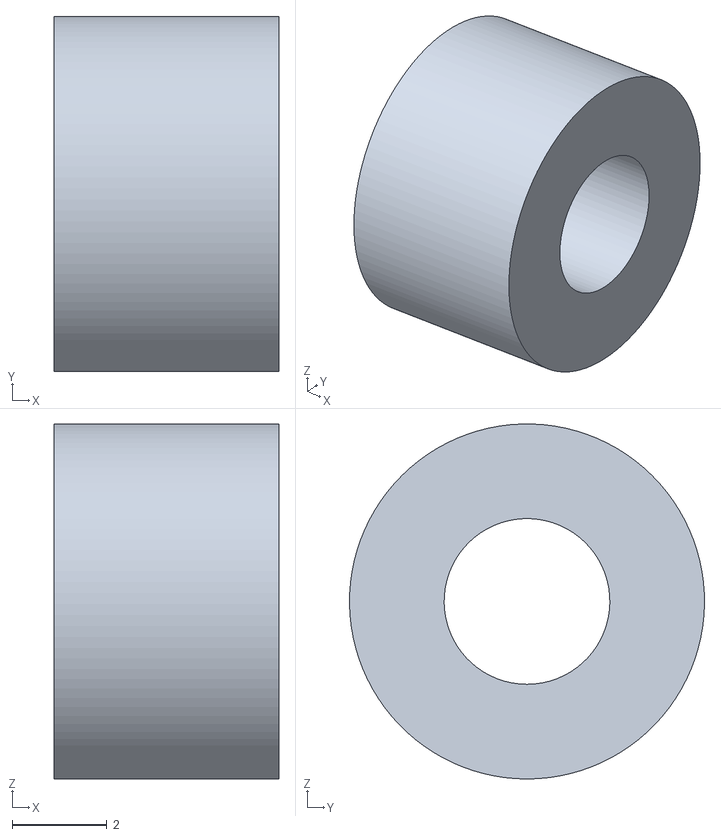
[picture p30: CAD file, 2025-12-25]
models/Spacer.stl
4.75 x 7.50 x 7.50

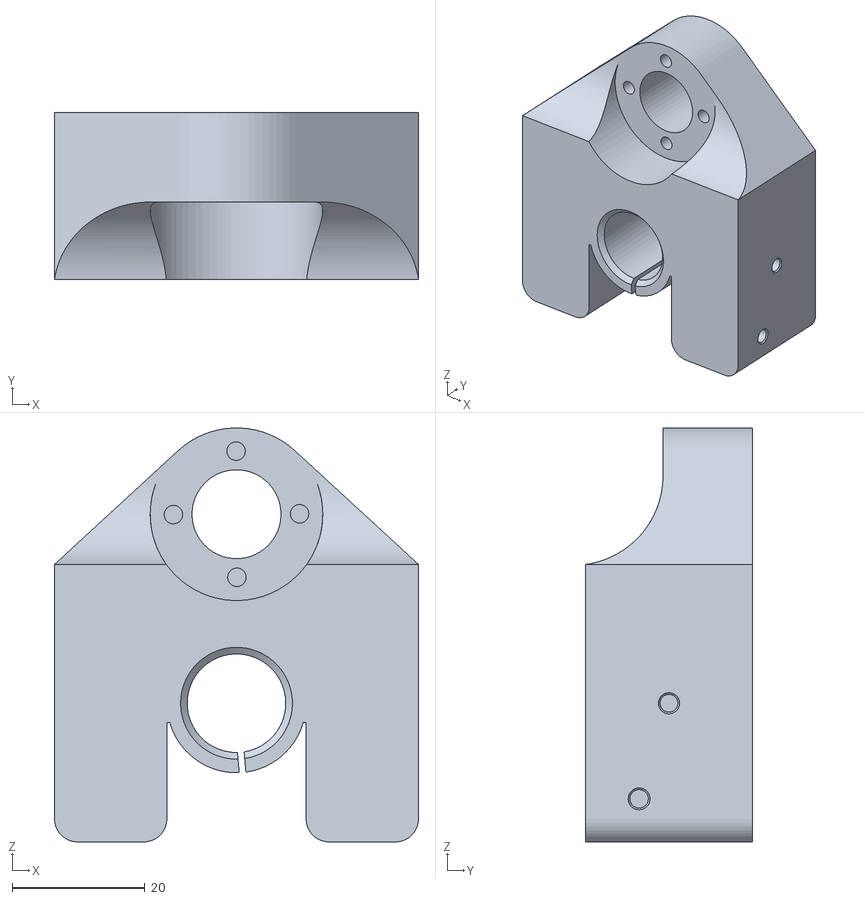
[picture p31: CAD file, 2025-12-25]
models/Z Axis Holder.stl
54.8 x 25.2 x 62.4

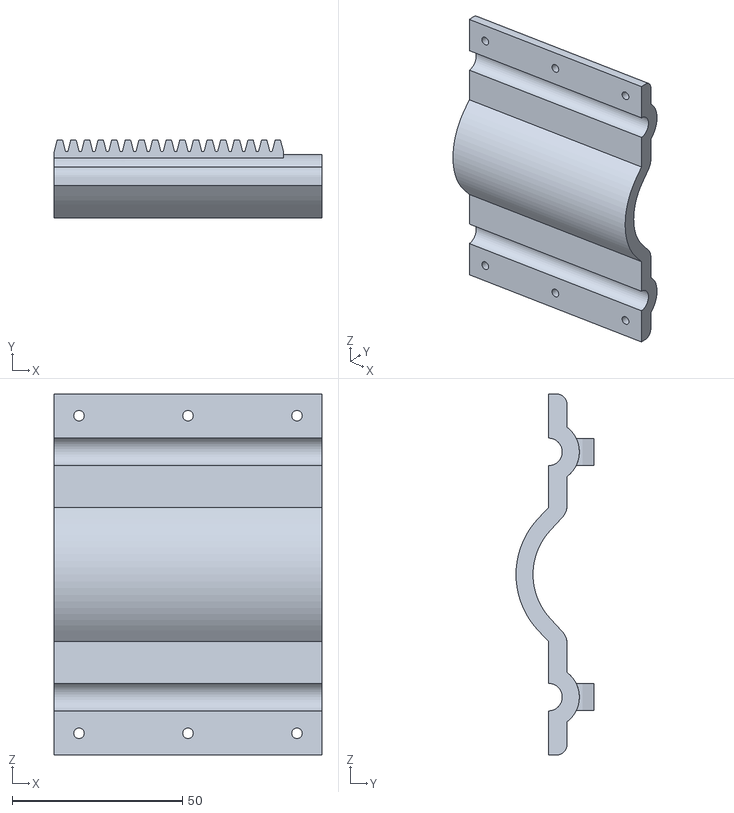
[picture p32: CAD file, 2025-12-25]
models/End Brake Part 1.stl
78.6 x 22.9 x 106.0

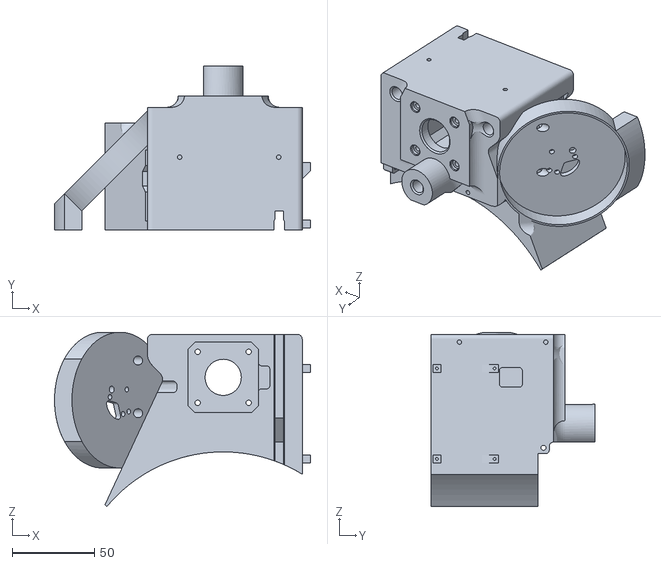
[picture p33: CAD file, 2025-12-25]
models/Z Axis Base.stl
155.5 x 99.4 x 106.0

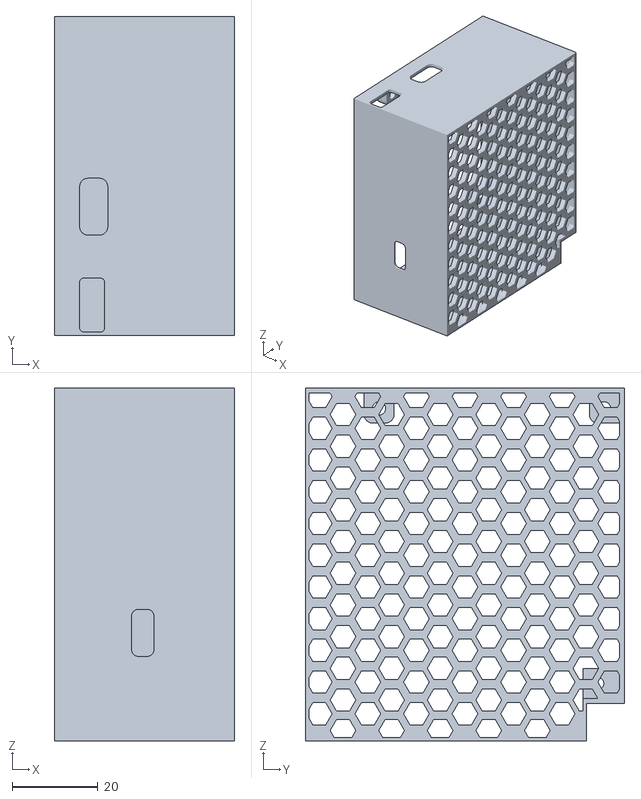
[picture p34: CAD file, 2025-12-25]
models/Electronics cover.stl
42.0 x 74.4 x 82.4

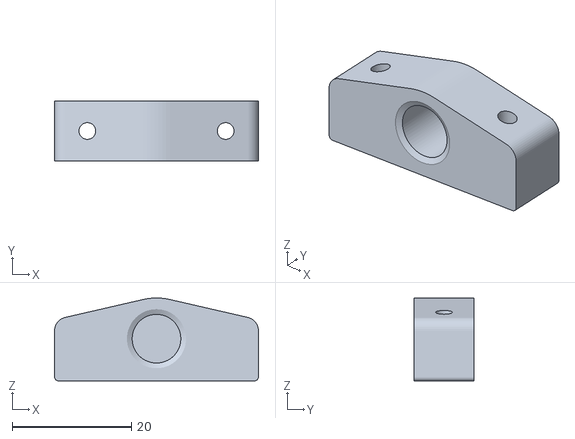
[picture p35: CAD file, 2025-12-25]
models/Tightener B.stl
34.2 x 10.0 x 13.9

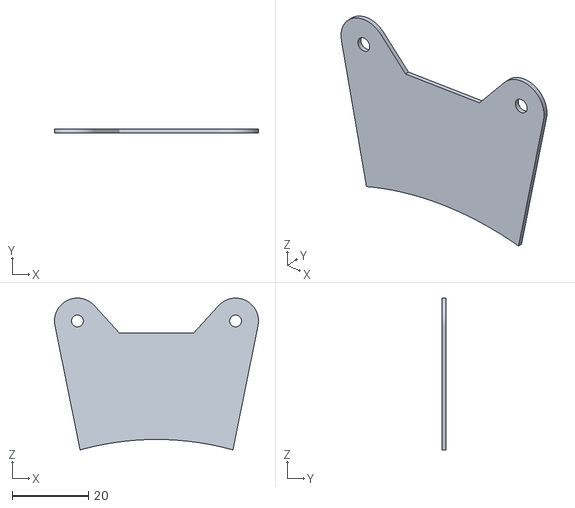
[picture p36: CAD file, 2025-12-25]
models/TeaPot spacer.stl
53.4 x 1.00 x 39.7

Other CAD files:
models/Left Arm Hand.stl
models/Left Arm Gear.stl

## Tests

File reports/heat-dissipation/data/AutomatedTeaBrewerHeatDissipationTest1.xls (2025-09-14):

Description:
Name: T1
Start: 25/09/11 20:58:02
Interval: 0min 1sec
Duration: 0day 9hrs 49min 14sec
Samples: 35355
Maximum: 98 | 3
Average: 38 | 2
Minimum: 25 | 8
Points:
No. Time Value
1 2025-09-11 20:58:02 98 | 2756958007813
2 2025-09-11 20:58:03 98 | 2756958007813
3 2025-09-11 20:58:04 98 | 2226867675781
4 2025-09-11 20:58:05 98 | 1431655883789
5 2025-09-11 20:58:06 98 | 1431655883789
6 2025-09-11 20:58:07 97 | 7985763549805
7 2025-09-11 20:58:08 98 | 1166610717773
8 2025-09-11 20:58:09 98 | 1166610717773
9 2025-09-11 20:58:10 98 | 1166610717773
10 2025-09-11 20:58:11 98 | 1431655883789
11 2025-09-11 20:58:12 98 | 1431655883789
12 2025-09-11 20:58:13 98 | 1431655883789
13 2025-09-11 20:58:14 98 | 1696701049805
14 2025-09-11 20:58:15 98 | 1696701049805
15 2025-09-11 20:58:16 98 | 0901412963867
16 2025-09-11 20:58:17 97 | 9311141967773
17 2025-09-11 20:58:18 97 | 9311141967773
18 2025-09-11 20:58:19 97 | 9576110839844
19 2025-09-11 20:58:20 97 | 9576110839844
20 2025-09-11 20:58:21 97 | 9576110839844
21 2025-09-11 20:58:22 97 | 6925506591797
22 2025-09-11 20:58:23 97 | 6925506591797
23 2025-09-11 20:58:24 97 | 9311141967773
24 2025-09-11 20:58:25 98 | 0106201171875
25 2025-09-11 20:58:26 98 | 0106201171875
26 2025-09-11 20:58:27 97 | 9662322998047
27 2025-09-11 20:58:28 97 | 8515853881836
28 2025-09-11 20:58:29 97 | 8515853881836
29 2025-09-11 20:58:30 97 | 8602066040039
30 2025-09-11 20:58:31 98 | 0371398925781
31 2025-09-11 20:58:32 98 | 0371398925781
32 2025-09-11 20:58:33 98 | 098762512207
33 2025-09-11 20:58:34 97 | 9662322998047
34 2025-09-11 20:58:35 97 | 9662322998047
35 2025-09-11 20:58:36 97 | 9311141967773
36 2025-09-11 20:58:37 97 | 7541809082031
37 2025-09-11 20:58:38 97 | 7541809082031
38 2025-09-11 20:58:39 97 | 8336868286133
39 2025-09-11 20:58:40 97 | 8336868286133
40 2025-09-11 20:58:41 98 | 0192413330078
41 2025-09-11 20:58:42 98 | 0192413330078
42 2025-09-11 20:58:43 98 | 0192413330078
43 2025-09-11 20:58:44 98 | 0457382202148
44 2025-09-11 20:58:45 98 | 1252670288086
45 2025-09-11 20:58:46 98 | 1252670288086
46 2025-09-11 20:58:47 98 | 0192413330078
47 2025-09-11 20:58:48 97 | 8867034912109
48 2025-09-11 20:58:49 97 | 8867034912109
49 2025-09-11 20:58:50 97 | 6746520996094
50 2025-09-11 20:58:51 97 | 8071823120117
51 2025-09-11 20:58:52 97 | 8071823120117
52 2025-09-11 20:58:53 97 | 8602066040039
53 2025-09-11 20:58:54 97 | 8602066040039
54 2025-09-11 20:58:55 97 | 8602066040039
55 2025-09-11 20:58:56 97 | 8336868286133
56 2025-09-11 20:58:57 97 | 8336868286133
57 2025-09-11 20:58:58 97 | 7806777954102
58 2025-09-11 20:58:59 97 | 8602066040039
59 2025-09-11 20:59:00 97 | 8602066040039
60 2025-09-11 20:59:01 97 | 8071823120117
61 2025-09-11 20:59:02 97 | 3035583496094
62 2025-09-11 20:59:03 97 | 3035583496094
63 2025-09-11 20:59:04 97 | 7276611328125
64 2025-09-11 20:59:05 97 | 8071823120117
65 2025-09-11 20:59:06 97 | 8071823120117
66 2025-09-11 20:59:07 97 | 7276611328125
67 2025-09-11 20:59:08 97 | 7806777954102
68 2025-09-11 20:59:09 97 | 7806777954102
69 2025-09-11 20:59:10 97 | 4891052246094
70 2025-09-11 20:59:11 97 | 4891052246094
71 2025-09-11 20:59:12 97 | 5686264038086
72 2025-09-11 20:59:13 97 | 6746520996094
73 2025-09-11 20:59:14 97 | 6746520996094
74 2025-09-11 20:59:15 97 | 5156097412109
75 2025-09-11 20:59:16 97 | 5421142578125
76 2025-09-11 20:59:17 97 | 5421142578125
77 2025-09-11 20:59:18 97 | 5156097412109
78 2025-09-11 20:59:19 97 | 5686264038086
79 2025-09-11 20:59:20 97 | 5686264038086
80 2025-09-11 20:59:21 97 | 5421142578125
81 2025-09-11 20:59:22 97 | 2240371704102
82 2025-09-11 20:59:23 97 | 2240371704102
83 2025-09-11 20:59:24 97 | 6481475830078
84 2025-09-11 20:59:25 97 | 7011566162109
85 2025-09-11 20:59:26 97 | 7011566162109
86 2025-09-11 20:59:27 97 | 4891052246094
87 2025-09-11 20:59:28 97 | 6037368774414
88 2025-09-11 20:59:29 97 | 6037368774414
89 2025-09-11 20:59:30 97 | 5421142578125
90 2025-09-11 20:59:31 97 | 5421142578125
91 2025-09-11 20:59:32 97 | 5951309204102
92 2025-09-11 20:59:33 97 | 3300628662109
93 2025-09-11 20:59:34 97 | 3300628662109
94 2025-09-11 20:59:35 97 | 4360885620117
95 2025-09-11 20:59:36 97 | 3300628662109
96 2025-09-11 20:59:37 97 | 3300628662109
97 2025-09-11 20:59:38 97 | 3300628662109
98 2025-09-11 20:59:39 97 | 3386688232422
99 2025-09-11 20:59:40 97 | 3386688232422
100 2025-09-11 20:59:41 97 | 1001129150391
101 2025-09-11 20:59:42 97 | 4095840454102
102 2025-09-11 20:59:43 97 | 4095840454102
103 2025-09-11 20:59:44 97 | 5242233276367
104 2025-09-11 20:59:45 97 | 4626007080078
105 2025-09-11 20:59:46 97 | 4626007080078
106 2025-09-11 20:59:47 97 | 2770462036133
107 2025-09-11 20:59:48 97 | 2770462036133
108 2025-09-11 20:59:49 97 | 4977188110352
109 2025-09-11 20:59:50 97 | 5507278442383
110 2025-09-11 20:59:51 97 | 5507278442383
111 2025-09-11 20:59:52 97 | 4712066650391
112 2025-09-11 20:59:53 97 | 3651809692383
113 2025-09-11 20:59:54 97 | 3651809692383
114 2025-09-11 20:59:55 97 | 2326431274414
115 2025-09-11 20:59:56 97 | 3035583496094
116 2025-09-11 20:59:57 97 | 3035583496094
117 2025-09-11 20:59:58 97 | 3386688232422
118 2025-09-11 20:59:59 97 | 3651809692383
119 2025-09-11 21:00:00 97 | 3651809692383
120 2025-09-11 21:00:01 97 | 0205917358398
121 2025-09-11 21:00:02 97 | 259147644043
122 2025-09-11 21:00:03 97 | 259147644043
123 2025-09-11 21:00:04 97 | 3651809692383
124 2025-09-11 21:00:05 97 | 3651809692383
125 2025-09-11 21:00:06 97 | 4181976318359
126 2025-09-11 21:00:07 97 | 2856674194336
127 2025-09-11 21:00:08 97 | 2856674194336
128 2025-09-11 21:00:09 97 | 3121719360352
129 2025-09-11 21:00:10 97 | 0470962524414
130 2025-09-11 21:00:11 97 | 0470962524414
131 2025-09-11 21:00:12 97 | 1266174316406
132 2025-09-11 21:00:13 97 | 0649948120117
133 2025-09-11 21:00:14 97 | 0649948120117
134 2025-09-11 21:00:15 97 | 073600769043
135 2025-09-11 21:00:16 97 | 2326431274414
136 2025-09-11 21:00:17 97 | 2326431274414
137 2025-09-11 21:00:18 97 | 073600769043
138 2025-09-11 21:00:19 96 | 7290115356445
139 2025-09-11 21:00:20 96 | 7290115356445
140 2025-09-11 21:00:21 96 | 9145660400391
141 2025-09-11 21:00:22 96 | 9145660400391
142 2025-09-11 21:00:23 97 | 0470962524414
143 2025-09-11 21:00:24 97 | 1796417236328
144 2025-09-11 21:00:25 97 | 1796417236328
145 2025-09-11 21:00:26 97 | 1266174316406
146 2025-09-11 21:00:27 96 | 9410705566406
147 2025-09-11 21:00:28 96 | 9410705566406
148 2025-09-11 21:00:29 96 | 9410705566406
149 2025-09-11 21:00:30 97 | 2326431274414
150 2025-09-11 21:00:31 97 | 2326431274414
151 2025-09-11 21:00:32 96 | 9145660400391
152 2025-09-11 21:00:33 96 | 7820358276367
153 2025-09-11 21:00:34 96 | 7820358276367
154 2025-09-11 21:00:35 96 | 8615493774414
155 2025-09-11 21:00:36 96 | 8615493774414
156 2025-09-11 21:00:37 96 | 8615493774414
157 2025-09-11 21:00:38 96 | 8085403442383
158 2025-09-11 21:00:39 96 | 8085403442383
159 2025-09-11 21:00:40 96 | 7555236816406
160 2025-09-11 21:00:41 96 | 9145660400391
161 2025-09-11 21:00:42 96 | 9145660400391
162 2025-09-11 21:00:43 96 | 8615493774414
163 2025-09-11 21:00:44 96 | 9410705566406
164 2025-09-11 21:00:45 96 | 9410705566406
165 2025-09-11 21:00:46 96 | 8085403442383
166 2025-09-11 21:00:47 96 | 8350448608398
167 2025-09-11 21:00:48 96 | 8350448608398
168 2025-09-11 21:00:49 96 | 8880615234375
169 2025-09-11 21:00:50 96 | 8880615234375
170 2025-09-11 21:00:51 96 | 8880615234375
171 2025-09-11 21:00:52 96 | 7290115356445
172 2025-09-11 21:00:53 96 | 4904556274414
173 2025-09-11 21:00:54 96 | 4904556274414
174 2025-09-11 21:00:55 96 | 7025146484375
175 2025-09-11 21:00:56 96 | 7025146484375
176 2025-09-11 21:00:57 96 | 7025146484375
177 2025-09-11 21:00:58 96 | 7555236816406
178 2025-09-11 21:00:59 96 | 7555236816406
179 2025-09-11 21:01:00 96 | 7290115356445
180 2025-09-11 21:01:01 96 | 5434646606445
181 2025-09-11 21:01:02 96 | 5434646606445
182 2025-09-11 21:01:03 96 | 1988830566406
183 2025-09-11 21:01:04 96 | 6760101318359
184 2025-09-11 21:01:05 96 | 6760101318359
185 2025-09-11 21:01:06 96 | 6229858398438
186 2025-09-11 21:01:07 96 | 7290115356445
187 2025-09-11 21:01:08 96 | 7290115356445
188 2025-09-11 21:01:09 96 | 5699844360352
189 2025-09-11 21:01:10 96 | 3844299316406
190 2025-09-11 21:01:11 96 | 3844299316406
191 2025-09-11 21:01:12 96 | 4904556274414
192 2025-09-11 21:01:13 96 | 5434646606445
193 2025-09-11 21:01:14 96 | 5434646606445
194 2025-09-11 21:01:15 96 | 6229858398438
195 2025-09-11 21:01:16 96 | 6229858398438
196 2025-09-11 21:01:17 96 | 4374389648438
197 2025-09-11 21:01:18 96 | 331413269043
198 2025-09-11 21:01:19 96 | 331413269043
199 2025-09-11 21:01:20 96 | 1193542480469
200 2025-09-11 21:01:21 96 | 4109344482422
201 2025-09-11 21:01:22 96 | 4109344482422
202 2025-09-11 21:01:23 96 | 4374389648438
203 2025-09-11 21:01:24 96 | 3579177856445
204 2025-09-11 21:01:25 96 | 3579177856445
205 2025-09-11 21:01:26 96 | 2784042358398
206 2025-09-11 21:01:27 96 | 2784042358398
207 2025-09-11 21:01:28 96 | 2784042358398
208 2025-09-11 21:01:29 96 | 331413269043
209 2025-09-11 21:01:30 96 | 1723785400391
210 2025-09-11 21:01:31 96 | 1723785400391
211 2025-09-11 21:01:32 96 | 0663528442383
212 2025-09-11 21:01:33 96 | 0663528442383
213 2025-09-11 21:01:34 96 | 2253875732422
214 2025-09-11 21:01:35 96 | 3579177856445
215 2025-09-11 21:01:36 96 | 3579177856445
216 2025-09-11 21:01:37 96 | 4109344482422
217 2025-09-11 21:01:38 96 | 2253875732422
218 2025-09-11 21:01:39 96 | 2253875732422
219 2025-09-11 21:01:40 95 | 8012771606445
220 2025-09-11 21:01:41 96 | 0133285522461
221 2025-09-11 21:01:42 96 | 0133285522461
222 2025-09-11 21:01:43 96 | 2253875732422
223 2025-09-11 21:01:44 95 | 8012771606445
224 2025-09-11 21:01:45 95 | 8012771606445
225 2025-09-11 21:01:46 96 | 0133285522461
226 2025-09-11 21:01:47 96 | 0133285522461
227 2025-09-11 21:01:48 95 | 9603271484375
228 2025-09-11 21:01:49 96 | 0398330688477
229 2025-09-11 21:01:50 96 | 0398330688477
230 2025-09-11 21:01:51 96 | 1193542480469
231 2025-09-11 21:01:52 96 | 1458740234375
232 2025-09-11 21:01:53 96 | 1458740234375
233 2025-09-11 21:01:54 95 | 774772644043
234 2025-09-11 21:01:55 95 | 8807983398438
235 2025-09-11 21:01:56 95 | 8807983398438
236 2025-09-11 21:01:57 95 | 9603271484375
237 2025-09-11 21:01:58 95 | 8012771606445
238 2025-09-11 21:01:59 95 | 8012771606445
239 2025-09-11 21:02:00 95 | 6687469482422
240 2025-09-11 21:02:01 95 | 8012771606445
241 2025-09-11 21:02:02 95 | 8012771606445
242 2025-09-11 21:02:03 95 | 8277816772461
243 2025-09-11 21:02:04 95 | 8277816772461
244 2025-09-11 21:02:05 95 | 9603271484375
245 2025-09-11 21:02:06 95 | 774772644043
246 2025-09-11 21:02:07 95 | 774772644043
247 2025-09-11 21:02:08 95 | 7482681274414
248 2025-09-11 21:02:09 95 | 774772644043
249 2025-09-11 21:02:10 95 | 774772644043
250 2025-09-11 21:02:11 95 | 6952514648438
251 2025-09-11 21:02:12 95 | 7482681274414
252 2025-09-11 21:02:13 95 | 7482681274414
253 2025-09-11 21:02:14 95 | 6422424316406
254 2025-09-11 21:02:15 95 | 4566955566406
255 2025-09-11 21:02:16 95 | 4566955566406
256 2025-09-11 21:02:17 95 | 5627212524414
257 2025-09-11 21:02:18 95 | 5627212524414
258 2025-09-11 21:02:19 95 | 5627212524414
259 2025-09-11 21:02:20 95 | 5362167358398
260 2025-09-11 21:02:21 95 | 5362167358398
261 2025-09-11 21:02:22 95 | 5362167358398
262 2025-09-11 21:02:23 95 | 5362167358398
263 2025-09-11 21:02:24 95 | 5362167358398
264 2025-09-11 21:02:25 95 | 5627212524414
265 2025-09-11 21:02:26 95 | 43017578125
266 2025-09-11 21:02:27 95 | 43017578125
267 2025-09-11 21:02:28 95 | 5627212524414
268 2025-09-11 21:02:29 95 | 4036712646484
269 2025-09-11 21:02:30 95 | 4036712646484
270 2025-09-11 21:02:31 95 | 0855941772461
271 2025-09-11 21:02:32 95 | 2711410522461
272 2025-09-11 21:02:33 95 | 2711410522461
273 2025-09-11 21:02:34 95 | 4832000732422
274 2025-09-11 21:02:35 95 | 5096969604492
275 2025-09-11 21:02:36 95 | 5096969604492
276 2025-09-11 21:02:37 95 | 3506698608398
277 2025-09-11 21:02:38 95 | 43017578125
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

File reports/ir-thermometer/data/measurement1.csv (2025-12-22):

IR Temperature | NTC Temperature
25.5 | 25.3
30 | 31
31 | 32
31.3 | 33.7
32 | 34.1
33 | 35.2
33.9 | 36.2
35.1 | 36.5
49.6 | 52.4
49.5 | 53.5
50.2 | 52.9
51.2 | 54
52.7 | 56.9
53.2 | 55.6
54 | 57.7
55.8 | 58.9
56.2 | 60.1
57.2 | 60
57.8 | 60.2
58.8 | 62.4
59.5 | 63
59.8 | 62.4
60.1 | 63.8
61 | 65.2
61.5 | 64.7
61.9 | 65.8
62.2 | 66.9
64.5 | 69.9
65.4 | 70.4
65.8 | 71.5
66.9 | 72.7
68 | 73.6
68.5 | 74
69.3 | 74.5
70.5 | 75.7
69.2 | 75.2
70.1 | 75.7
71.6 | 77
72.5 | 77.9
72.9 | 78
73.6 | 79.3
74.4 | 79.8
75.2 | 80.1
75.9 | 81.9
76.3 | 82.5
77.1 | 82.3
77.8 | 83.8
78.6 | 84.4
79.1 | 84.6
79.4 | 85.3
80.3 | 85.9
81 | 86.6
81.6 | 87.5
82.1 | 87.8
82.4 | 88.2
83.3 | 88.6
84 | 89.0
84.2 | 90.2
84.7 | 91
85 | 91.3
85.3 | 91.5
85.6 | 92.4
86 | 92.5
86.5 | 93.5
87.2 | 94
87.5 | 94.8
88.2 | 95.5
88.9 | 96
89.1 | 97
89.8 | 96.7
90.1 | 97.9
90.4 | 97.9
90.9 | 98.3
91.2 | 98.5
91.3 | 99
91.9 | 99.2
92.2 | 99.2
92.3 | 98.8
93.4 | 99.3
18.65 | 19.15
18.91 | 19.01
18.59 | 18.98
18.85 | 18.98
18.63 | 19.05
18.63 | 19.05
18.55 | 19.05
18.85 | 19.05
18.81 | 19.05
18.65 | 19.05
18.75 | 19.02
18.95 | 19.02
18.95 | 19.05
18.81 | 19.02
18.87 | 19.02
18.71 | 19.05
18.59 | 19.05
18.65 | 19.05
18.75 | 19.05
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

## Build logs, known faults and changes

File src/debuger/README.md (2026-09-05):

# Automated Tea Brewer Hardware Debugger (`debuger`)

This project is a dedicated interactive debugger and diagnostic tool for:
1. **TMC2130 Stepper Motor Driver** (SPI + GPIO)
2. **D8563TS / PCF8563 Real-Time Clock** (I2C address `0x51`)
3. **VL53L0CXV0DH/1 (VL53L0X) Laser Distance Sensor** (I2C address `0x29`)
4. **MLX90614ESF-DCC Non-Contact IR Thermometer** (I2C address `0x5A`)
5. **Induction Cooker Power Control** (`PIN_INDUCTION` = `GPIO 3`)

---

## 📌 Features

### 🔥 Induction Cooker Control
- **Manual ON / OFF (`ind on` / `ind off`)**: Turns the heating plate output HIGH or LOW.
- **Toggle State (`ind` / `ind tog`)**: Quickly toggles the heating plate state between ON and OFF.
- **Momentary Pulse (`ind pulse [ms]`)**: Simulates a momentary button press (e.g. `ind pulse 200` for optocoupler button triggers).

### 🌡️ MLX90614 Non-Contact IR Thermometer Testing
- **Single Temperature Test (`temp` / `ir` / `mlx`)**: Reads ambient temp, raw object temp, and calibrated tea brewing temperature in °C and °F.
- **Live Real-Time Thermal Stream (`temp mon` / `ir mon`)**: Continuous 10 Hz thermal stream with live thermal ASCII gauge.

### 📏 VL53L0X Laser Distance Sensor Testing
- **Single Distance Measurement (`dist` / `tof` / `laser`)**: Reads accurate distance in mm, cm, and inches.
- **Live Real-Time Distance Stream (`dist mon` / `tof mon`)**: Continuous 10 Hz telemetry stream with live proximity ASCII gauge bar.

### 🕒 D8563TS / PCF8563 I2C RTC Testing
- **I2C Bus Scanner (`scan` / `i2c`)**: Scans all 127 I2C addresses and identifies connected chips (e.g. `0x51` D8563TS RTC, `0x29` VL53L0X, `0x5A` MLX90614, `0x68` DS1307).
- **RTC Diagnostic & Register Dump (`rtc` / `rtctest`)**: Probes `0x51`, dumps all 16 raw registers (`0x00`-`0x0F`), decodes status flags (VL voltage low, STOP bit, alarm/timer flags) and parsed date/time.
- **Live 1-Second Ticking Stream (`rtc mon` / `rtc stream`)**: Live stream of current seconds to verify that the 32.768 kHz crystal oscillator is running.
- **Set RTC Time (`rtc set <timestamp>` or `rtc set Y M D h m s`)**: Sets date & time and clears STOP/VL bits so counting starts.
- **Automatic Internet Time Sync (`sync_time.py`)**: Python script to sync ESP32 RTC to network/NTP time with 1 command.

### ⚙️ TMC2130 Stepper Motor Control & Tuning
- **Direct Hardware Testing & Diagnostics**:
  - SPI communication verification test (`test` / `selftest`).
  - Read driver status, StallGuard values, errors (overtemp, open load, short to ground).
  - Enable / disable motor coils directly (`enable` / `disable`).
  - Raw pulse stepping with configurable step count and pulse delays (`step <n> [delay_us]`).
- **Full Motion Control**:
  - StallGuard2-based sensorless endstop calibration (`cal` / `c`).
  - Calibration with live real-time StallGuard stream (`calmon` / `t`).
  - Fast homing (`home` / `f`).
  - Move to percentage `0% - 100%` (e.g. `50`).
  - Move to absolute step position (`pos <steps>`).
  - Immediate emergency stop (`stop` / `x`).
- **Live Telemetry Monitoring**:
  - Real-time streaming monitor (`monitor` / `m`) displaying time, position in steps, position %, StallGuard load value (0–1023), and movement state.
- **Sensorless StallGuard Tuning**:
  - Live threshold adjustment (`sgt <val>`, `+` / `-` to fine-tune).
- **Persistent Calibration**:
  - Save to NVS Flash (`save` / `w`).
  - Load from NVS Flash (`load` / `l`).
  - Erase from NVS Flash (`clear` / `z`).

---

## 🔌 Hardware Pinout

| Function | ESP32-C6 Pin | Connected Device Pin |
|---|---|---|
| **I2C SDA** | `GPIO 22` | `D8563TS SDA` |
| **I2C SCL** | `GPIO 23` | `D8563TS SCL` |
| **Motor EN** | `GPIO 2` | `TMC2130 EN` (Active LOW) |
| **Motor DIR** | `GPIO 0` | `TMC2130 DIR` |
| **Motor STEP** | `GPIO 1` | `TMC2130 STEP` |
| **Motor CS** | `GPIO 21` | `TMC2130 CS` / `SS` |
| **SPI SCLK** | `GPIO 19` | `TMC2130 SCK` |
| **SPI MOSI** | `GPIO 18` | `TMC2130 SDI` |
| **SPI MISO** | `GPIO 20` | `TMC2130 SDO` |

---

## 💻 CLI Commands Reference

Connect via USB Serial JTAG / Serial Terminal (115200 baud):

```text
================ TMC2130, RTC, TOF & IR DEBUGGER ================
[MLX90614 IR TEMPERATURE SENSOR]
  temp / ir     - Single non-contact IR temperature test
  temp mon      - Live real-time thermal telemetry stream

[VL53L0X LASER DISTANCE SENSOR]
  dist / tof    - Single laser distance measurement (mm)
  dist mon      - Live real-time distance telemetry stream

[D8563TS I2C RTC COMMANDS]
  scan / i2c    - Scan I2C bus and list all detected devices
  rtc / rtctest - Test D8563TS chip & dump all 16 registers
  rtc mon       - Live 1-second ticking stream test
  rtc set <ts | Y M D h m s> - Set custom time or Unix timestamp

[STEPPER MOTOR COMMANDS]
  c / cal       - Full calibration (finds endpoints, run WITHOUT load)
  t / calmon    - Calibration with live StallGuard monitor
  f / home      - Fast homing (returns to start endpoint)
  <0-100>       - Move to percentage (e.g. '50', '100', '0')
  pos <steps>   - Move to absolute step position (e.g. 'pos 1600')
  step <n> [us] - Raw manual step pulse test (e.g. 'step 400 300')
  x / stop      - Emergency stop & hold
  e / enable    - Enable motor driver coil power
  d / disable   - Disable motor driver (freewheel)

[DIAGNOSTICS & TUNING]
  s / status    - Print comprehensive status for motor & RTC
  m / monitor   - Start live real-time StallGuard telemetry stream
  g / sg        - Single StallGuard reading (0-1023)
  sgt <val>     - Set StallGuard threshold (-64 to +63)
  + / -         - Increase / Decrease SGT threshold
  test          - Run automated hardware self-test routine

[CALIBRATION STORAGE]
  w / save      - Save calibration parameters to NVS Flash
  l / load      - Load calibration parameters from NVS Flash
  z / clear     - Clear calibration parameters from NVS Flash
  h / help      - Print help menu
============================================================
```

---

## 🚀 Building & Flashing

From the `src/debuger` folder:

```powershell
idf.py build flash monitor -p COM6
```

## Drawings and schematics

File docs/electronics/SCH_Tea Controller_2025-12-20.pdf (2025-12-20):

### Stepper Motor Driver

### MCU

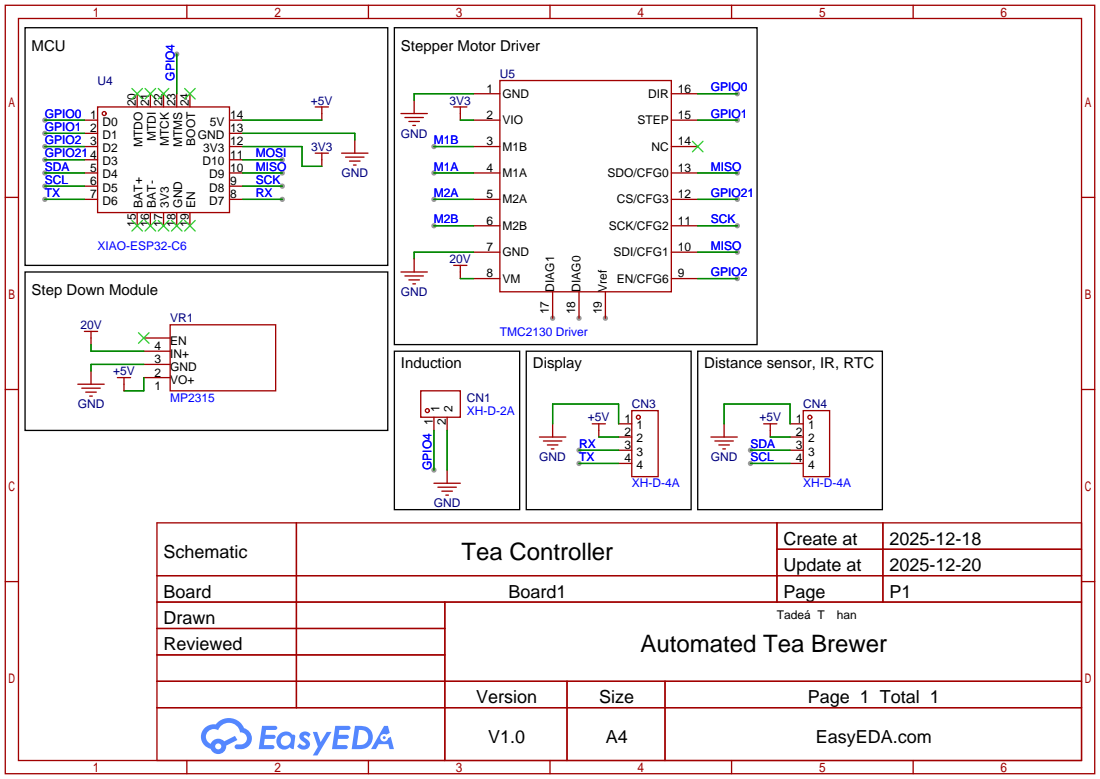
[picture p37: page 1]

Schematic | Tea Controller | Create at | 2025-12-18

Update at | 2025-12-20

Board | Board1 | Page | P1
Drawn | | Tadeá T han Automated Tea Brewer
Reviewed

Version | Size | Page 1 Total 1
V1.0 | A4 | EasyEDA.com

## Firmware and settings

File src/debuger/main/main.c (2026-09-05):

/**
 * @file main.c
 * @brief Stepper Motor TMC2130 & D8563TS RTC Debugger and Diagnostic Tool
 * 
 * Interactive debugger for TMC2130 stepper motor driver and D8563TS / PCF8563 I2C RTC.
 * Compatible with ESP32, ESP32-C6, ESP32-S3 via USB Serial JTAG / UART Console.
 */

#include <stdio.h>
#include <string.h>
#include <stdlib.h>
#include <stdarg.h>
#include <ctype.h>
#include "freertos/FreeRTOS.h"
#include "freertos/task.h"
#include "esp_log.h"
#include "esp_timer.h"
#include "nvs_flash.h"
#include "driver/gpio.h"
#include "driver/uart.h"
#include "soc/soc_caps.h"

#if SOC_USB_SERIAL_JTAG_SUPPORTED
#include "driver/usb_serial_jtag.h"
#endif

#include "main_pins.h"
#include "tmc2130.h"
#include "motor_control.h"
#include "d8563.h"
#include "distance_sensor.h"
#include "mlx90614.h"

static const char *TAG = "DEBUGGER";

#define RX_BUF_SIZE 512

/* ============================================================================
   CONSOLE I/O IMPLEMENTATION (Exclusively USB CDC / USB Serial JTAG)
   ============================================================================ */

#if SOC_USB_SERIAL_JTAG_SUPPORTED
static bool usb_serial_initialized = false;
#endif

esp_err_t console_init(void)
{
#if SOC_USB_SERIAL_JTAG_SUPPORTED
    usb_serial_jtag_driver_config_t config = {
        .rx_buffer_size = RX_BUF_SIZE,
        .tx_buffer_size = RX_BUF_SIZE,
    };
    if (usb_serial_jtag_driver_install(&config) == ESP_OK) {
        usb_serial_initialized = true;
    }
#endif
    return ESP_OK;
}

void console_print(const char *str)
{
#if SOC_USB_SERIAL_JTAG_SUPPORTED
    if (usb_serial_initialized) {
        usb_serial_jtag_write_bytes((const uint8_t *)str, strlen(str), pdMS_TO_TICKS(100));
    }
#endif
}

void console_printf(const char *fmt, ...)
{
    char buf[512];
    va_list args;
    va_start(args, fmt);
    vsnprintf(buf, sizeof(buf), fmt, args);
    va_end(args);
    console_print(buf);
}

int console_getchar_timeout(uint32_t timeout_ms)
{
#if SOC_USB_SERIAL_JTAG_SUPPORTED
    if (usb_serial_initialized) {
        uint8_t c;
        int len = usb_serial_jtag_read_bytes(&c, 1, pdMS_TO_TICKS(timeout_ms));
        if (len > 0) return (int)c;
    }
#endif
    return -1;
}

int console_getchar(void)
{
    return console_getchar_timeout(0);
}

bool console_has_input(void)
{
#if SOC_USB_SERIAL_JTAG_SUPPORTED
    if (usb_serial_initialized) {
        uint8_t c;
        int len = usb_serial_jtag_read_bytes(&c, 1, 0);
        if (len > 0) return true;
    }
#endif
    return false;
}

/* ============================================================================
   TMC2130 DIAGNOSTIC & REGISTER DECODING FUNCTIONS
   ============================================================================ */

/**
 * @brief Print full detailed status from DRV_STATUS register
 */
static void print_drv_status_details(void)
{
    uint16_t sg = motor_read_stallguard();
    motor_status_t st;
    motor_get_status(&st);

    console_printf("\r\n================ TMC2130 DRV_STATUS ================\r\n");
    console_printf("  Driver Connection : %s\r\n", motor_test_connection() ? "ONLINE (OK)" : "OFFLINE / NO RESPONSE");
    console_printf("  StallGuard Result : %u / 1023\r\n", sg);
    console_printf("  SGT Threshold     : %d\r\n", st.sgt_threshold);
    console_printf("  Position          : %ld steps (%.1f%%)\r\n", (long)st.position_steps, st.position_percent);
    console_printf("  Total Range       : %ld steps\r\n", (long)st.total_steps);
    console_printf("  Calibrated / Homed: %s / %s\r\n", st.is_calibrated ? "YES" : "NO", st.is_homed ? "YES" : "NO");
    console_printf("  Current State     : %s\r\n", 
                   st.state == MOTOR_STATE_IDLE ? "IDLE" :
                   st.state == MOTOR_STATE_MOVING ? "MOVING" :
                   st.state == MOTOR_STATE_HOMING ? "HOMING" :
                   st.state == MOTOR_STATE_CALIBRATING ? "CALIBRATING" : "ERROR");

    if (st.error != MOTOR_ERROR_NONE) {
        console_printf("  Active Error      : %s\r\n",
                       st.error == MOTOR_ERROR_NOT_CALIBRATED ? "NOT CALIBRATED" :
                       st.error == MOTOR_ERROR_NOT_HOMED ? "NOT HOMED" :
                       st.error == MOTOR_ERROR_STALL_DETECTED ? "STALL DETECTED" :
                       st.error == MOTOR_ERROR_DRIVER_FAULT ? "DRIVER FAULT" :
                       st.error == MOTOR_ERROR_OVERTEMP ? "OVER-TEMPERATURE" : "UNKNOWN");
    } else {
        console_printf("  Active Error      : NONE\r\n");
    }
    console_printf("====================================================\r\n\r\n");
}

/**
 * @brief Live monitor task: streams StallGuard and status until user presses a key
 */
static void run_live_monitor(void)
{
    console_printf("\r\n--- LIVE MOTOR TELEMETRY (Press any key to exit) ---\r\n");
    console_printf("   Time(s) | Steps   |  Percent | StallGuard | Moving\r\n");
    console_printf("----------------------------------------------------\r\n");

    uint32_t start_ms = (uint32_t)(esp_timer_get_time() / 1000);

    while (1) {
        if (console_getchar() >= 0) {
            break;
        }

        uint32_t now_ms = (uint32_t)(esp_timer_get_time() / 1000) - start_ms;
        uint16_t sg = motor_read_stallguard();
        int32_t pos = motor_get_position_steps();
        float pct = motor_get_position_percent();
        bool moving = motor_is_moving();

        console_printf("  %6.2f s | %7ld | %7.1f%% |    %4u    | %s\r\n",
                       (float)now_ms / 1000.0f,
                       (long)pos,
                       pct >= 0 ? pct : 0.0f,
                       sg,
                       moving ? "YES" : "NO");

        vTaskDelay(pdMS_TO_TICKS(150));
    }
    console_printf("--- Monitor stopped ---\r\n\r\n");
}

/**
 * @brief Automated Stepper Motor Self-Test Routine
 */
static void run_self_test(void)
{
    console_printf("\r\n================ RUNNING MOTOR SELF TEST ================\r\n");
    
    // Step 1: SPI connection
    console_printf("[1/4] Checking TMC2130 SPI connection... ");
    bool connected = motor_test_connection();
    if (connected) {
        console_printf("PASS [OK]\r\n");
    } else {
        console_printf("FAIL [SPI NOT RESPONDING]\r\n");
        console_printf("      Check wiring: MOSI=%d, MISO=%d, SCLK=%d, CS=%d\r\n",
                       PIN_SPI_MOSI, PIN_SPI_MISO, PIN_SPI_SCLK, PIN_MOTOR_CS);
        return;
    }

    // Step 2: StallGuard reading test
    console_printf("[2/4] Reading StallGuard value... ");
    uint16_t sg = motor_read_stallguard();
    console_printf("PASS (Value: %u)\r\n", sg);

    // Step 3: Enable driver
    console_printf("[3/4] Enabling motor driver coil output... ");
    motor_enable();
    vTaskDelay(pdMS_TO_TICKS(100));
    console_printf("PASS [OK]\r\n");

    // Step 4: Small forward and backward nudge
    console_printf("[4/4] Performing small step nudge (forward & back)... ");
    for (int i = 0; i < 200; i++) {
        gpio_set_level(PIN_MOTOR_DIR, 1);
        gpio_set_level(PIN_MOTOR_STEP, 1);
        esp_rom_delay_us(100);
        gpio_set_level(PIN_MOTOR_STEP, 0);
        esp_rom_delay_us(100);
    }
    vTaskDelay(pdMS_TO_TICKS(50));
    for (int i = 0; i < 200; i++) {
        gpio_set_level(PIN_MOTOR_DIR, 0);
        gpio_set_level(PIN_MOTOR_STEP, 1);
        esp_rom_delay_us(100);
        gpio_set_level(PIN_MOTOR_STEP, 0);
        esp_rom_delay_us(100);
    }
    console_printf("PASS [OK]\r\n");

    console_printf("================ SELF TEST COMPLETE ================\r\n\r\n");
}

/* ============================================================================
   D8563TS I2C RTC DIAGNOSTIC & TESTING FUNCTIONS
   ============================================================================ */

/**
 * @brief Run full D8563TS test & register dump
 */
static void run_d8563_test(void)
{
    gpio_num_t sda, scl;
    d8563_get_pins(&sda, &scl, NULL);

    console_printf("\r\n================ D8563TS I2C RTC TEST ================\r\n");
    console_printf("Target Address : 0x51 (SDA: GPIO %d, SCL: GPIO %d)\r\n", sda, scl);

    bool connected = d8563_is_connected();
    if (!connected) {
        console_printf("Result         : [FAILED] Device not responding at 0x51!\r\n\r\n");
        d8563_diagnose_bus();
        return;
    }

    console_printf("Result         : [PASS] D8563TS detected and responding!\r\n\r\n");

    d8563_status_t st;
    if (d8563_get_status(&st) == ESP_OK) {
        console_printf("--- Raw Register Dump (0x00 - 0x0F) ---\r\n");
        for (int i = 0; i < 16; i++) {
            console_printf("  [0x%02X] = 0x%02X", i, st.raw_regs[i]);
            if ((i + 1) % 4 == 0) console_printf("\r\n");
        }
        console_printf("\r\n");

        console_printf("--- Decoded Status & Time ---\r\n");
        console_printf("  Oscillator State : %s\r\n", st.is_running ? "RUNNING (STOP=0)" : "STOPPED (STOP=1)");
        console_printf("  Voltage Low (VL) : %s %s\r\n", 
                       st.voltage_low ? "YES (Power was lost / Battery low)" : "NO (Clock integrity guaranteed)",
                       st.voltage_low ? "[!] Run 'rtc now' or 'rtc set' to initialize time" : "");
        console_printf("  Current Time     : %04d-%02d-%02d %02d:%02d:%02d (%s)\r\n",
                       st.time.year, st.time.month, st.time.day,
                       st.time.hour, st.time.minute, st.time.second,
                       d8563_weekday_name(st.time.weekday));
        console_printf("  Control 1 / 2    : 0x%02X / 0x%02X\r\n", st.raw_regs[0], st.raw_regs[1]);
        console_printf("  CLKOUT Control   : 0x%02X\r\n", st.raw_regs[0x0D]);
        console_printf("  Timer Control    : 0x%02X (Val: 0x%02X)\r\n", st.raw_regs[0x0E], st.raw_regs[0x0F]);
    } else {
        console_printf("[ERROR] Failed to read registers from D8563!\r\n");
    }

    console_printf("======================================================\r\n\r\n");
}

/**
 * @brief Live RTC time stream to confirm 32.768 kHz oscillator ticking
 */
static void run_d8563_stream(void)
{
    if (!d8563_is_connected()) {
        console_printf("[ERROR] D8563TS not detected on I2C bus at 0x51!\r\n");
        return;
    }

    console_printf("\r\n--- LIVE D8563TS RTC STREAM (Press any key to exit) ---\r\n");
    console_printf(" Date       Time       Weekday    VL Flag   Status\r\n");
    console_printf("----------------------------------------------------\r\n");

    int last_sec = -1;
    while (1) {
        if (console_getchar() >= 0) {
            break;
        }

        d8563_time_t t;
        if (d8563_get_time(&t) == ESP_OK) {
            if (t.second != last_sec) {
                last_sec = t.second;
                console_printf(" %04d-%02d-%02d %02d:%02d:%02d  %-9s  VL=%d       Ticking OK\r\n",
                               t.year, t.month, t.day,
                               t.hour, t.minute, t.second,
                               d8563_weekday_name(t.weekday),
                               t.voltage_low ? 1 : 0);
            }
        } else {
            console_printf(" [ERROR reading RTC]\r\n");
        }

        vTaskDelay(pdMS_TO_TICKS(100));
    }
    console_printf("--- RTC Stream stopped ---\r\n\r\n");
}

/* ============================================================================
   VL53L0X LASER DISTANCE SENSOR FUNCTIONS
   ============================================================================ */

static void run_distance_test(void)
{
    console_printf("\r\n================ VL53L0X LASER DISTANCE SENSOR TEST ================\r\n");
    console_printf("Target Address : 0x29 (SDA: GPIO %d, SCL: GPIO %d)\r\n", PIN_I2C_SDA, PIN_I2C_SCL);

    if (!distance_sensor_is_initialized()) {
        console_printf("Initializing VL53L0X sensor... ");
        esp_err_t err = distance_sensor_init(NULL);
        if (err != ESP_OK) {
            console_printf("FAIL (%s)\r\n", esp_err_to_name(err));
            console_printf("Check if sensor is connected to VCC, GND, SDA (GPIO %d), SCL (GPIO %d).\r\n\r\n",
                           PIN_I2C_SDA, PIN_I2C_SCL);
            return;
        }
        console_printf("OK [ONLINE]\r\n");
    }

    uint16_t dist_mm = 0;
    console_printf("Measuring distance... ");
    esp_err_t err = distance_sensor_get_distance(&dist_mm);
    if (err == ESP_OK) {
        float dist_cm = (float)dist_mm / 10.0f;
        float dist_in = (float)dist_mm / 25.4f;
        console_printf("SUCCESS!\r\n");
        console_printf("  Distance : %u mm  (%.1f cm / %.2f in)\r\n", dist_mm, dist_cm, dist_in);
        if (dist_mm >= 8190) {
            console_printf("  Status   : [OUT OF RANGE / NO TARGET]\r\n");
        } else {
            console_printf("  Status   : [TARGET DETECTED - VALID]\r\n");
        }
    } else {
        console_printf("FAIL (%s)\r\n", esp_err_to_name(err));
    }
    console_printf("====================================================================\r\n\r\n");
}

static void run_distance_stream(void)
{
    console_printf("\r\n--- Starting VL53L0X Live Distance Stream (Press any key or 'q' to stop) ---\r\n");

    if (!distance_sensor_is_initialized()) {
        console_printf("Initializing VL53L0X sensor... ");
        esp_err_t err = distance_sensor_init(NULL);
        if (err != ESP_OK) {
            console_printf("FAIL (%s)\r\n\r\n", esp_err_to_name(err));
            return;
        }
        console_printf("OK [ONLINE]\r\n");
    }

    console_printf("  Elapsed | Distance (mm) | Distance (cm) | Proximity Gauge\r\n");
    console_printf(" ---------+---------------+---------------+------------------------------------\r\n");

    int64_t start_us = esp_timer_get_time();
    while (1) {
        if (console_getchar() >= 0) {
            break;
        }

        uint16_t dist_mm = 0;
        esp_err_t err = distance_sensor_get_distance(&dist_mm);
        int64_t now_ms = (esp_timer_get_time() - start_us) / 1000;

        if (err == ESP_OK) {
            char bar[31];
            int bars = dist_mm / 25;
            if (bars > 30) bars = 30;
            for (int i = 0; i < bars; i++) bar[i] = '=';
            bar[bars] = '\0';

            if (dist_mm >= 8190) {
                console_printf("  %6.2f s |     OUT       |      OUT      | [OUT OF RANGE]\r\n", (float)now_ms / 1000.0f);
            } else {
                console_printf("  %6.2f s |   %5u mm     |   %6.1f cm   | [|%-30s]\r\n",
                               (float)now_ms / 1000.0f, dist_mm, (float)dist_mm / 10.0f, bar);
            }
        } else {
            console_printf("  %6.2f s | [READ ERROR: %s]\r\n", (float)now_ms / 1000.0f, esp_err_to_name(err));
        }

        vTaskDelay(pdMS_TO_TICKS(100));
    }
    console_printf("--- Distance Stream stopped ---\r\n\r\n");
}

/* ============================================================================
   MLX90614 NON-CONTACT INFRARED THERMOMETER FUNCTIONS
   ============================================================================ */

static void run_thermometer_test(void)
{
    console_printf("\r\n================ MLX90614 IR THERMOMETER TEST ================\r\n");
    console_printf("Target Address : 0x5A (SDA: GPIO %d, SCL: GPIO %d)\r\n", PIN_I2C_SDA, PIN_I2C_SCL);

    mlx90614_readings_t readings;
    esp_err_t err = mlx90614_get_readings(&readings);
    if (err == ESP_OK) {
        float amb_f = (readings.ambient_c * 9.0f / 5.0f) + 32.0f;
        float obj_raw_f = (readings.object_raw_c * 9.0f / 5.0f) + 32.0f;
        float obj_calib_f = (readings.object_calib_c * 9.0f / 5.0f) + 32.0f;

        console_printf("Status         : [ONLINE] Communication OK\r\n");
        console_printf("  Ambient Temp : %6.1f °C  (%6.1f °F)\r\n", readings.ambient_c, amb_f);
        console_printf("  Object (Raw) : %6.1f °C  (%6.1f °F)\r\n", readings.object_raw_c, obj_raw_f);
        console_printf("  Object (Cal) : %6.1f °C  (%6.1f °F) [Calibrated for Tea Liquid]\r\n",
                       readings.object_calib_c, obj_calib_f);
    } else {
        console_printf("Status         : [FAILED] No response at 0x5A!\r\n");
        console_printf("Check if sensor is connected to VCC (3.3V), GND, SDA (GPIO %d), SCL (GPIO %d).\r\n",
                       PIN_I2C_SDA, PIN_I2C_SCL);
    }
    console_printf("==============================================================\r\n\r\n");
}

static void run_thermometer_stream(void)
{
    console_printf("\r\n--- Starting MLX90614 Live Temperature Stream (Press any key to exit) ---\r\n");
    console_printf("  Elapsed | Ambient (°C) | Raw IR (°C) | Calibrated (°C) | Thermal Gauge (0-100°C)\r\n");
    console_printf(" ---------+--------------+-------------+-----------------+------------------------------------\r\n");

    int64_t start_us = esp_timer_get_time();
    while (1) {
        if (console_getchar() >= 0) {
            break;
        }

        mlx90614_readings_t readings;
        esp_err_t err = mlx90614_get_readings(&readings);
        int64_t now_ms = (esp_timer_get_time() - start_us) / 1000;

        if (err == ESP_OK) {
            char bar[31];
            int bars = (int)(readings.object_calib_c / 3.33f);
            if (bars < 0) bars = 0;
            if (bars > 30) bars = 30;
            for (int i = 0; i < bars; i++) bar[i] = '#';
            bar[bars] = '\0';

            console_printf("  %6.2f s |    %5.1f °C  |   %5.1f °C  |     %5.1f °C    | [|%-30s]\r\n",
                           (float)now_ms / 1000.0f,
                           readings.ambient_c,
                           readings.object_raw_c,
                           readings.object_calib_c,
                           bar);
        } else {
            console_printf("  %6.2f s | [READ ERROR: %s]\r\n", (float)now_ms / 1000.0f, esp_err_to_name(err));
        }

        vTaskDelay(pdMS_TO_TICKS(150));
    }
    console_printf("--- Temperature Stream stopped ---\r\n\r\n");
}

/* ============================================================================
   INDUCTION COOKER CONTROL (PIN_INDUCTION = GPIO 3)
   ============================================================================ */

static bool s_induction_enabled = false;

static void induction_init(void)
{
    gpio_config_t io_conf = {
        .pin_bit_mask = (1ULL << PIN_INDUCTION),
        .mode = GPIO_MODE_OUTPUT,
        .pull_up_en = GPIO_PULLUP_DISABLE,
        .pull_down_en = GPIO_PULLDOWN_ENABLE,
        .intr_type = GPIO_INTR_DISABLE,
    };
    gpio_config(&io_conf);
    gpio_set_level(PIN_INDUCTION, 0);
    s_induction_enabled = false;
}
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
void app_main(void)
{
    ESP_LOGI(TAG, "Starting Debugger Application...");

    // Initialize NVS
    esp_err_t ret = nvs_flash_init();
    if (ret == ESP_ERR_NVS_NO_FREE_PAGES || ret == ESP_ERR_NVS_NEW_VERSION_FOUND) {
        ESP_ERROR_CHECK(nvs_flash_erase());
        ESP_ERROR_CHECK(nvs_flash_init());
    }

    // Initialize Universal Console (USB Serial JTAG + UART0)
    console_init();
    vTaskDelay(pdMS_TO_TICKS(500));

    console_printf("\r\n\r\n");
    console_printf("============================================================\r\n");
    console_printf("  AUTOMATED TEA BREWER - MOTOR & D8563TS RTC DEBUGGER       \r\n");
    console_printf("============================================================\r\n");

    // Initialize Stepper Motor Controller
    console_printf("[1/5] Initializing TMC2130 driver & gptimer...\r\n");
    ret = motor_init();
    if (ret == ESP_OK) {
        console_printf("      -> Motor subsystem: OK\r\n");
    } else {
        console_printf("      -> Motor subsystem: FAILED (%s)\r\n", esp_err_to_name(ret));
    }

    // Attempt loading saved calibration from NVS
    ret = motor_load_calibration();
    if (ret == ESP_OK) {
        console_printf("      -> Motor Calibration: LOADED\r\n");
    } else {
        console_printf("      -> Motor Calibration: NONE (Run 'cal' to calibrate)\r\n");
    }

    // Initialize D8563TS I2C RTC Module
    console_printf("[2/5] Initializing D8563TS I2C RTC (SDA: GPIO %d, SCL: GPIO %d)...\r\n",
                   PIN_I2C_SDA, PIN_I2C_SCL);
    ret = d8563_init(PIN_I2C_SDA, PIN_I2C_SCL, 50000);
    if (ret == ESP_OK) {
        if (d8563_is_connected()) {
            console_printf("      -> D8563TS RTC (0x51): ONLINE (OK)\r\n");
        } else {
            console_printf("      -> D8563TS RTC (0x51): NOT DETECTED (Run 'scan' to inspect bus)\r\n");
        }
    } else {
        console_printf("      -> I2C Bus Init: FAILED (%s)\r\n", esp_err_to_name(ret));
    }

    // Initialize VL53L0X Laser Distance Sensor
    console_printf("[3/5] Initializing VL53L0X Laser Distance Sensor (0x29)...\r\n");
    ret = distance_sensor_init(NULL);
    if (ret == ESP_OK) {
        console_printf("      -> VL53L0X ToF (0x29): ONLINE (OK)\r\n");
    } else {
        console_printf("      -> VL53L0X ToF (0x29): NOT DETECTED (Run 'scan' / 'dist' to test)\r\n");
    }

    // Initialize MLX90614 Infrared Temperature Sensor
    console_printf("[4/6] Initializing MLX90614 IR Thermometer (0x5A)...\r\n");
    ret = mlx90614_init(PIN_I2C_SDA, PIN_I2C_SCL);
    if (ret == ESP_OK) {
        console_printf("      -> MLX90614 IR (0x5A): ONLINE (OK)\r\n");
    } else {
        console_printf("      -> MLX90614 IR (0x5A): NOT DETECTED (Run 'scan' / 'temp' to test)\r\n");
    }

    // Initialize Induction Cooker Control Pin
    console_printf("[5/6] Initializing Induction Cooker Control (GPIO %d)...\r\n", PIN_INDUCTION);
    induction_init();
    console_printf("      -> Induction Cooker Pin (GPIO %d): READY (OFF)\r\n", PIN_INDUCTION);

    console_printf("[6/6] Starting Interactive CLI Console...\r\n\r\n");

    // Create interactive debugger console task
    xTaskCreate(console_task, "dbg_console", 4096, NULL, 5, NULL);
}

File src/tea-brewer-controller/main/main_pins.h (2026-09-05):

/**
 * @file pins.h
 * @brief Pin definitions for Tea Brewer Controller
 */

#ifndef PINS_H
#define PINS_H

/* ============================================
   TMC2130 STEPPER DRIVER PINS
   ============================================ */
                           // M1   M2
#define PIN_MOTOR_EN        18 // 2
#define PIN_MOTOR_DIR       19 // 6
#define PIN_MOTOR_STEP      20 // 7
#define PIN_MOTOR_CS        21 // 11 

/* ============================================
   SPI PINS (for TMC2130)
   ============================================ */
#define PIN_SPI_SCLK        10
#define PIN_SPI_MOSI        1
#define PIN_SPI_MISO        0

/* ============================================
   UART0 PINS (ESP-to-ESP communication)
   ============================================ */
#define PIN_UART_TX         16
#define PIN_UART_RX         17

/* ============================================
   I2C PINS (for MLX90614 Temperature Sensor)
   ============================================ */
#define PIN_I2C_SDA         22
#define PIN_I2C_SCL         23

/* ============================================
   INDUCTION COOKER CONTROL PIN
   ============================================ */
#define PIN_INDUCTION       3  // HIGH = ON, LOW = OFF

#endif // PINS_H

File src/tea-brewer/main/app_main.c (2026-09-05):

/*
 * SPDX-FileCopyrightText: 2023 Espressif Systems (Shanghai) CO LTD
 *
 * SPDX-License-Identifier: CC0-1.0
 */

#include <stdio.h>
#include <string.h>
#include <math.h>
#include "freertos/FreeRTOS.h"
#include "freertos/task.h"
#include "esp_system.h"
#include "esp_heap_caps.h"
#include "nvs_flash.h"
#include "driver/gpio.h"
#include "esp_log.h"

#include "settings.h"
#include "bsp/esp-bsp.h"
#include "esp_lvgl_port.h"
#include "driver/i2c.h"
#include "esp_lcd_touch_cst816s.h"

#include "demos/lv_demos.h"
#include "demos/keypad_encoder/lv_demo_keypad_encoder.h"
#include "iot_knob.h"

#include "uart_comm.h"
#include "ui/ui.h"
#include "ui/ui_events.h"
#include "webserver.h"
#include "wifi_config.h"

static const char *TAG = "main";

#define DEVICE_NAME "TeaBrewer"

/* Startup sequence state */
static bool startup_homing_triggered = false;
static bool startup_sequence_complete = false;

//NOTE: We currently have two versions of the 2.1 knob screen. If you have purchased the touch version, please set the macro definition below to 1

#define MEMORY_MONITOR 0

#if MEMORY_MONITOR

#define ARRAY_SIZE_OFFSET   5   //Increase this if print_real_time_stats returns ESP_ERR_INVALID_SIZE

/**
 * @brief   Function to print the CPU usage of tasks over a given duration.
 */
static esp_err_t print_real_time_stats(TickType_t xTicksToWait)
{
    TaskStatus_t *start_array = NULL, *end_array = NULL;
    UBaseType_t start_array_size, end_array_size;
    uint32_t start_run_time, end_run_time;
    esp_err_t ret;

    //Allocate array to store current task states
    start_array_size = uxTaskGetNumberOfTasks() + ARRAY_SIZE_OFFSET;
    start_array = malloc(sizeof(TaskStatus_t) * start_array_size);
    if (start_array == NULL) {
        ret = ESP_ERR_NO_MEM;
        goto exit;
    }
    //Get current task states
    start_array_size = uxTaskGetSystemState(start_array, start_array_size, &start_run_time);
    if (start_array_size == 0) {
        ret = ESP_ERR_INVALID_SIZE;
        goto exit;
    }

    vTaskDelay(xTicksToWait);

    //Allocate array to store tasks states post delay
    end_array_size = uxTaskGetNumberOfTasks() + ARRAY_SIZE_OFFSET;
    end_array = malloc(sizeof(TaskStatus_t) * end_array_size);
    if (end_array == NULL) {
        ret = ESP_ERR_NO_MEM;
        goto exit;
    }
    //Get post delay task states
    end_array_size = uxTaskGetSystemState(end_array, end_array_size, &end_run_time);
    if (end_array_size == 0) {
        ret = ESP_ERR_INVALID_SIZE;
        goto exit;
    }

    //Calculate total_elapsed_time in units of run time stats clock period.
    uint32_t total_elapsed_time = (end_run_time - start_run_time);
    if (total_elapsed_time == 0) {
        ret = ESP_ERR_INVALID_STATE;
        goto exit;
    }

    printf("| Task \t\t| Run Time \t| Percentage\n");
    //Match each task in start_array to those in the end_array
    for (int i = 0; i < start_array_size; i++) {
        int k = -1;
        for (int j = 0; j < end_array_size; j++) {
            if (start_array[i].xHandle == end_array[j].xHandle) {
                k = j;
                //Mark that task have been matched by overwriting their handles
                start_array[i].xHandle = NULL;
                end_array[j].xHandle = NULL;
                break;
            }
        }
        //Check if matching task found
        if (k >= 0) {
            uint32_t task_elapsed_time = end_array[k].ulRunTimeCounter - start_array[i].ulRunTimeCounter;
            uint32_t percentage_time = (task_elapsed_time * 100UL) / (total_elapsed_time * portNUM_PROCESSORS);
            printf("| %s \t\t| %d \t| %d%%\n", start_array[i].pcTaskName, task_elapsed_time, percentage_time);
        }
    }

    //Print unmatched tasks
    for (int i = 0; i < start_array_size; i++) {
        if (start_array[i].xHandle != NULL) {
            printf("| %s | Deleted\n", start_array[i].pcTaskName);
        }
    }
    for (int i = 0; i < end_array_size; i++) {
        if (end_array[i].xHandle != NULL) {
            printf("| %s | Created\n", end_array[i].pcTaskName);
        }
    }
    ret = ESP_OK;

exit:    //Common return path
    free(start_array);
    free(end_array);
    return ret;
}

static void monitor_task(void *arg)
{
    (void) arg;
    const int STATS_TICKS = pdMS_TO_TICKS(2 * 1000);

    while (true) {
        ESP_LOGI(TAG, "System Info Trace");
        printf("\tDescription\tInternal\tSPIRAM\n");
        printf("Current Free Memory\t%d\t\t%d\n",
               heap_caps_get_free_size(MALLOC_CAP_8BIT | MALLOC_CAP_INTERNAL),
               heap_caps_get_free_size(MALLOC_CAP_SPIRAM));
        printf("Largest Free Block\t%d\t\t%d\n",
               heap_caps_get_largest_free_block(MALLOC_CAP_8BIT | MALLOC_CAP_INTERNAL),
               heap_caps_get_largest_free_block(MALLOC_CAP_SPIRAM));
        printf("Min. Ever Free Size\t%d\t\t%d\n",
               heap_caps_get_minimum_free_size(MALLOC_CAP_8BIT | MALLOC_CAP_INTERNAL),
               heap_caps_get_minimum_free_size(MALLOC_CAP_SPIRAM));

        printf("Getting real time stats over %d ticks\n", STATS_TICKS);
        if (print_real_time_stats(STATS_TICKS) == ESP_OK) {
            printf("Real time stats obtained\n");
        } else {
            printf("Error getting real time stats\n");
        }

        vTaskDelay(STATS_TICKS);
    }

    vTaskDelete(NULL);
}

static void sys_monitor_start(void)
{
    BaseType_t ret_val = xTaskCreatePinnedToCore(monitor_task, "Monitor Task", 4 * 1024, NULL, configMAX_PRIORITIES - 3, NULL, 0);
    ESP_ERROR_CHECK_WITHOUT_ABORT((pdPASS == ret_val) ? ESP_OK : ESP_FAIL);
}
#endif

/* ============================================
   MOTOR COMMUNICATION CALLBACKS
   ============================================ */

/**
 * @brief Callback when motor status is updated
 */
static void on_motor_status_update(const motor_status_t *status)
{
    ESP_LOGI(TAG, "Motor status: pos=%.1f%%, cal=%d, home=%d, connected=%d",
             status->position_percent,
             status->is_calibrated,
             status->is_homed,
             status->is_connected);
    
    /* Notify UI about status update */
    ui_on_motor_status_update(status);
    
    /* Startup sequence: trigger homing when ESP #2 first connects */
    if (!startup_homing_triggered && status->is_connected && status->is_calibrated) {
        startup_homing_triggered = true;
        ESP_LOGI(TAG, "ESP #2 connected - triggering homing sequence...");
        vTaskDelay(pdMS_TO_TICKS(200));
        uart_comm_home();
    }
}

/**
 * @brief Callback when motor move is complete
 */
static void on_motor_move_complete(bool success)
{
    if (success) {
        ESP_LOGI(TAG, "Motor move completed");
    } else {
        ESP_LOGW(TAG, "Motor move failed");
    }
}
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

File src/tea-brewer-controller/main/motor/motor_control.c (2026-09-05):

/**
 * @file motor_control.c
 * @brief High-level motor control implementation
 */

#include "motor_control.h"
#include "tmc2130.h"
#include "../main_pins.h"
#include "freertos/FreeRTOS.h"
#include "freertos/task.h"
#include "driver/gptimer.h"
#include "nvs_flash.h"
#include "nvs.h"
#include "esp_timer.h"
#include "esp_log.h"

static const char *TAG = "MOTOR";

/* ============================================
   CONFIGURATION
   ============================================ */
#define MOTOR_RMS_CURRENT_MA    800
#define MOTOR_HOLD_MULTIPLIER   0.5f
#define MOTOR_MICROSTEPS        16
#define MOTOR_R_SENSE           0.11f
#define STEPS_PER_REV           200

#define HOMING_SPEED_RPM        30
#define NORMAL_SPEED_RPM        120
#define STALL_DEBOUNCE_MS       50
#define DEFAULT_BACKOFF_STEPS   100

/* NVS Keys */
#define NVS_NAMESPACE           "motor"
#define NVS_KEY_CALIBRATED      "cal"
#define NVS_KEY_TOTAL_STEPS     "steps"
#define NVS_KEY_SGT             "sgt"
#define NVS_KEY_BACKOFF         "backoff"

/* ============================================
   PRIVATE DATA
   ============================================ */
static tmc2130_handle_t tmc2130;
static gptimer_handle_t step_timer = NULL;

/* Motor state */
static volatile bool motor_running = false;
static volatile int32_t steps_remaining = 0;
static volatile bool step_state = false;
static volatile int32_t current_position = 0;
static volatile bool direction_forward = true;
static motor_state_t current_state = MOTOR_STATE_IDLE;
static motor_error_t current_error = MOTOR_ERROR_NONE;

/* Calibration data */
typedef struct {
    bool is_valid;
    int32_t total_steps;
    int32_t backoff_steps;
    int8_t sgt_threshold;
} calibration_t;

static calibration_t calibration = {
    .is_valid = false,
    .total_steps = 0,
    .backoff_steps = DEFAULT_BACKOFF_STEPS,
    .sgt_threshold = -6
};

static bool is_homed = false;
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

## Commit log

2025-09-14 Add heat dissipation data processing and visualization script
    [AutomatedTeaBrewerHeatDissipationTest1.xls]
2025-11-11 Add TMC2130 documentation to get driver to SPI mode.
2025-11-11 Add wiring diagram and detailed wiring instructions for TMC2130 stepper motor driver
2025-11-16 Init commit for espidf
    [partitions.csv]
2025-11-19 First big design change
    [partitions.csv]
2025-11-19 Add UART API for communication and initialize in app_main
2025-11-25 Stepper motor demo code
2025-11-25 Refactor TMC2130 control for sensorless homing and position management; add command handling and improve documentation
2025-11-25 Enhance motor control with non-blocking movement and improved task handling; adjust delays for better responsiveness
2025-11-25 Add TMC2130 stepper motor driver and binary protocol implementation
    - Implemented TMC2130 driver in `tmc2130.h` and `tmc2130.c` for controlling stepper motors via SPI.
    - Added functions for initialization, configuration, and status retrieval of the TMC2130 driver.
    - Created a binary protocol in `protocol.c` and `protocol.h` for ESP-to-ESP communication, including frame building and parsing.
    - Defined command IDs and error codes for communication between the display and motor controller.
    - Implemented CRC calculation for data integrity in protocol frames.
    [console.c, main.c, main_pins.h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]
2025-11-25 Rotary encoder working to control display
2025-11-25 feat: Add UART communication module for motor controller
    - Created uart_comm.h to define UART communication functions and motor status structures.
    - Implemented motor command functions including movement, calibration, and status retrieval.
    - Added callback registration for motor status updates and error notifications.
    feat: Integrate motor control into UI
    - Updated ui.c to include motor control logic, handling home and movement commands.
    - Added helper functions to update UI based on motor status.
    - Implemented callbacks for motor status updates and home completion.
    refactor: Enhance UI event handling
    - Modified ui_events.c to include NVS save task for batching writes.
    - Updated event ha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
    [app_main.c, uart_comm.c, uart_comm.h]
2025-11-27 feat: Implement MLX90614 temperature sensor integration and UART communication updates
2025-11-27 Add VL53L0X distance sensor driver and integrate with main application
    - Created distance_sensor.h for VL53L0X Time-of-Flight distance sensor driver, including initialization, deinitialization, and distance reading functions.
    - Updated main.c to initialize the distance sensor and create a task for periodic distance readings.
    - Added thermometer_get_bus_handle function to thermometer.c and thermometer.h to allow sharing the I2C bus with the distance sensor.
2025-11-27 Add data processing script and temperature comparison graph
    [measurement1.csv]
2025-11-28 feat: Implement pot sensor module and integrate with UART communication for pot presence detection
2025-12-01 feat: Add temperature calibration functionality to thermometer module
2025-12-03 Add wiring instructions for IR thermometer and laser distance sensor
2025-12-08 Refactor tea brewer settings and motor control
    - Updated settings structure to replace drying time and position with idle position.
    - Modified motor control functions to handle movement to idle position instead of drying position.
    - Implemented automatic homing sequence on startup for ESP #2.
    - Added debug functionality for teabag dropoff sequence.
    - Adjusted UI elements to reflect changes in idle position settings.
    - Cleaned up unused variables and functions related to drying time and position.
    - Enhanced logging for better traceability during motor operations.
    [app_main.c, main.c, uart_comm.c]
2025-12-08 feat: Add DS1307 RTC module with I2C integration and timezone support
2025-12-15 feat: Implement scheduling feature for tea brewing
    - Added scheduler functionality to allow users to set a brewing schedule.
    - Introduced new commands for setting, canceling, and getting schedule status.
    - Implemented StallGuard monitoring during motor calibration.
    - Enhanced console commands to include new features for calibration and status reporting.
    - Updated UART communication to handle new schedule commands and notifications.
    - Integrated schedule restoration on startup and UI updates for scheduled brewing.
    - Added persistent storage for schedule settings in NVS.
    - Improved logging for better debugging and user feedback during scheduling.
    [app_main.c, console.c, main.c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]
2025-12-15 Add inverse function for temperature decay and enhance graph plotting
2025-12-20 Add schematic diagram for the Automated Tea Brewer
2025-12-22 Update temperature data (measure more) and add new comparison graph.
    [measurement1.csv]
2025-12-22 Add brewing time calculation based on temperature and update scheduler logic
    [brew1.xls]
2025-12-23 feat: Add web server functionality for Tea Brewer dashboard
    - Implemented a web server to control the tea brewing process and display status.
    - Added API endpoints for getting and setting tea settings, starting/stopping brews, and scheduling.
    - Integrated mDNS for easy access to the dashboard via local network.
    - Enhanced UI with HTML/CSS for real-time updates on temperature, brew state, and tea selection.
    - Introduced functions to handle WiFi reset and idle position settings.
    - Updated CMakeLists.txt to include necessary dependencies for web server functionality.
    [app_main.c, webserver.c]
2025-12-25 Add 3D models.
    [Electronics cover.stl, End Brake Basket.stl, End Brake Part 1.stl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]
2025-12-25 Convert esp32-wifi-bootstrap to submodule
2026-09-01 feat(debuger): add hardware debugger tool and pin updates for PCB Rev0.1.0
    - Add interactive hardware debugger CLI for ESP32-C6
    - Add TMC2130 stepper motor driver testing & StallGuard calibration
    - Add D8563TS I2C RTC driver and internet time sync script
    - Add VL53L0X laser distance sensor support with shared bit-bang I2C
    - Add MLX90614 non-contact IR temperature sensor driver & telemetry
    - Add Induction Cooker power control (GPIO 3 ON/OFF, toggle, pulse)
    - Update main_pins.h pin mappings for PCB Rev0.1.0
    [d8563.c, distance_sensor.c, main.c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]
2026-09-01 feat(controller): update RTC driver to D8563TS/PCF8563 for PCB Rev0.1.0
    - Replace legacy DS1307 RTC driver with D8563TS / PCF8563 (0x51)
    - Use shared Open-Drain I2C engine for seamless bus sharing with ToF and IR sensors
    - Add sdkconfig.defaults and component requirements for ESP32-C6
    [rtc.c]
2026-09-01 fix(controller): disable background debug print spam and unify MLX90614 bit-bang I2C driver
    [main.c, thermometer.c]
2026-09-01 fix(controller): add power-on retry and match debugger sensor boot order for MLX90614
    [main.c, thermometer.c]
2026-09-05 feat: implement aggressive teabag dropoff sequence and CLI enhancements
    - Add configurable teabag dropoff sequence with up to 100 cycles and 800 RPM speed
    - Support motor movement up to 110% with bounds safety check
    - Add NVS persistence for dropoff configuration ('dropoff save'/'dropoff reset')
    - Add protocol CMD_TEABAG_DROPOFF handling over UART
    - Restrict interactive CLI exclusively to tea-brewer-controller
    - Add CLI command history with UP/DOWN arrow navigation
    - Add CLI inline editing with LEFT/RIGHT arrows, Home/End, Backspace, and Delete
    [app_main.c, bsp.c, bsp_lcd.c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]

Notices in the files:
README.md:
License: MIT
